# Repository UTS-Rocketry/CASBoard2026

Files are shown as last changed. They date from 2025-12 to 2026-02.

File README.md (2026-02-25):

# CAS Interface Board 2026

Control Actuation System (CAS) Interface Board for the UTS Rocketry avionics stack.

This board provides closed-loop control for the airbrake and roll control systems, along with sensor interfaces and onboard data logging. The design is based on the STM32F405RGT6 microcontroller and integrates inertial sensing, actuator control, and non-volatile storage.

The CAS board is intended to operate as part of the UTS Rocketry flight avionics architecture.

---

## Overview

The CAS Interface Board is responsible for:

- Airbrake deployment control
- Roll stabilization control
- Sensor acquisition
- Data logging
- Actuator interfacing

Closed-loop control is performed onboard using IMU and barometric sensor measurements.

---

## Hardware

### Microcontroller

STM32F405RGT6

- ARM Cortex-M4F
- 168 MHz
- Hardware floating point
- 1 MB Flash
- 192 KB RAM

---

### Sensors

#### IMU

LSM6DS3TR-C

Interface:

- SPI (4-wire)

Signals:

- SCK
- MOSI
- MISO
- CS
- DRDY Interrupt

Power:

- 3.3 V

---

#### Barometer

Interface:

- I2C

Signals:

- SCL
- SDA

Power:

- 3.3 V

---

### Storage

#### MicroSD Card

Interface:

- SPI

Signals:

- SCK
- MOSI
- MISO
- CS

Purpose:

- Flight data logging

---

#### External Flash

Interface:

- SPI

Purpose:

- Backup logging
- Blackbox storage

---

### Actuator Interfaces

#### Servo Outputs

- Airbrake Servo
- Roll Control Servo

Control Method:

- Timer PWM outputs

Power:

- Dedicated 5 V servo rail

Signal Voltage:

- 3.3 V logic

---

### Analog Inputs

#### Airbrake Position Feedback

External potentiometer input.

Signals:

- 3.3 V
- ADC Input
- GND

---

### Digital Inputs

#### Limit Switches

Digital inputs for actuator limits.

Typical configuration:

- External pull-down resistors
- GPIO input

---

#### IMU Interrupt

IMU data-ready interrupt.

Connected to STM32 EXTI input.

---

### Debug Interface

Serial Wire Debug (SWD)

Signals:

- SWDIO
- SWCLK
- NRST
- 3.3 V
- GND

Used for:

- Programming
- Debugging

---

## Communication Interfaces

### SPI Buses

SPI1

Used for:

- IMU

SPI2

Used for:

- MicroSD card
- External flash

---

### I2C Bus

I2C1

Used for:

- Barometer

---

## Power Architecture

### 3.3 V Rail

Supplies:

- MCU
- IMU
- Barometer
- Flash
- SD card logic

---

### 5 V Rail

Supplies:

- Servo motors

---

### Grounding

- Continuous ground plane
- Shared logic and servo ground

---

## Control System

### Airbrake Control

The CAS system predicts apogee using altitude and velocity estimates derived from sensor measurements.

Airbrake deployment is adjusted to reach the target apogee.

Inputs:

- Barometer altitude
- Estimated vertical velocity

Outputs:

- Airbrake servo PWM

---

### Roll Control

Roll stabilization is performed using gyroscope measurements from the IMU.

Inputs:

- Roll rate from IMU

Outputs:

- Roll control servo PWM

---

## Firmware

Development tools:

- STM32CubeMX
- STM32CubeIDE
- ST-Link

Features:

- SPI IMU driver
- I2C barometer driver
- PWM servo control
- SD card logging
- Flash logging
- Interrupt-driven sensor acquisition

---

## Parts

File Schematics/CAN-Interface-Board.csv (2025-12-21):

Reference | Qty | Value | DNP | Exclude from BOM | Exclude from Board | Footprint | Datasheet
0.015Ohm? | 1 | C4293416 |  |  |  |  | ~
10uF? | 1 | C426118 |  |  |  | Capacitor_SMD:C_01005_0402Metric_Pad0.57x0.30mm_HandSolder | ~
100nF1,100nF2,100nF3,100nF? | 4 | C6565120 |  |  |  | Capacitor_SMD:C_1210_3225Metric_Pad1.33x2.70mm_HandSolder | ~
120R? | 1 | C4353191 |  |  |  | Resistor_SMD:R_0603_1608Metric | ~
C15742 | 1 | STM32F405RGTx |  |  |  | Package_QFP:LQFP-64_10x10mm_P0.5mm | https://www.st.com/resource/en/datasheet/stm32f405rg.pdf
INA180A2 | 1 | C192764 |  |  |  | Package_TO_SOT_SMD:SOT-23-5 | http://www.ti.com/lit/ds/symlink/ina180.pdf
LD1117S33TR? | 1 | C86781 |  |  |  | Package_TO_SOT_SMD:SOT-223-3_TabPin2 | http://www.st.com/st-web-ui/static/active/en/resource/technical/document/datasheet/CD00000544.pdf
SN65HVD230 | 1 | C12084 |  |  |  | Package_SO:SOIC-8_3.9x4.9mm_P1.27mm | http://www.ti.com/lit/ds/symlink/sn65hvd230.pdf

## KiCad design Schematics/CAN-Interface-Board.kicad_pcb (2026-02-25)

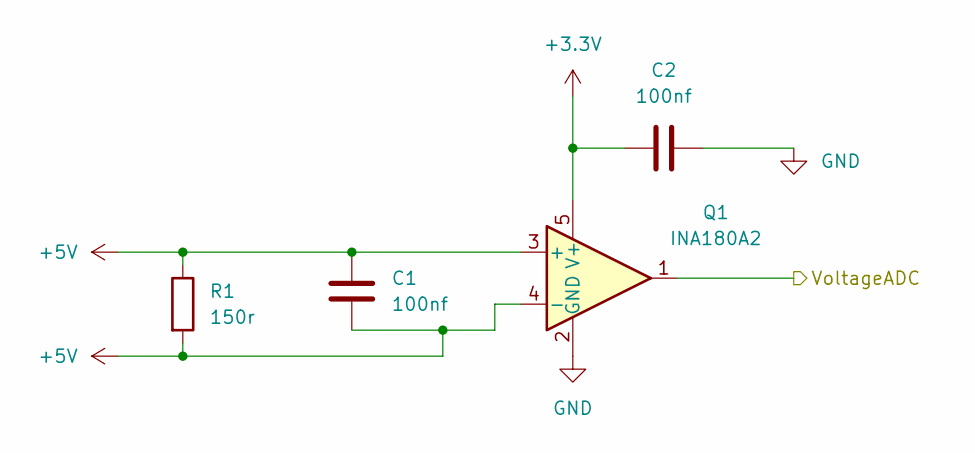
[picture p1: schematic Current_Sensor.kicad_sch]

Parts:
C1, C2: 100nf; C_0805_2012Metric_Pad1.18x1.45mm_HandSolder; LCSC Part C49678
Q1: INA180A2; SOT-23-5; LCSC Part C192764
R1: 150r; R_0805_2012Metric_Pad1.20x1.40mm_HandSolder; LCSC Part C4293416

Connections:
+3.3V: C2.1, Q1.5 (V+); also elsewhere on the board
+5V: C1.1, C1.2, Q1.3 (+), Q1.4 (-), R1.1, R1.2; also elsewhere on the board
/Current Sensor/VoltageADC: Q1.1; also elsewhere on the board
GND: C2.2, Q1.2 (GND); also elsewhere on the board

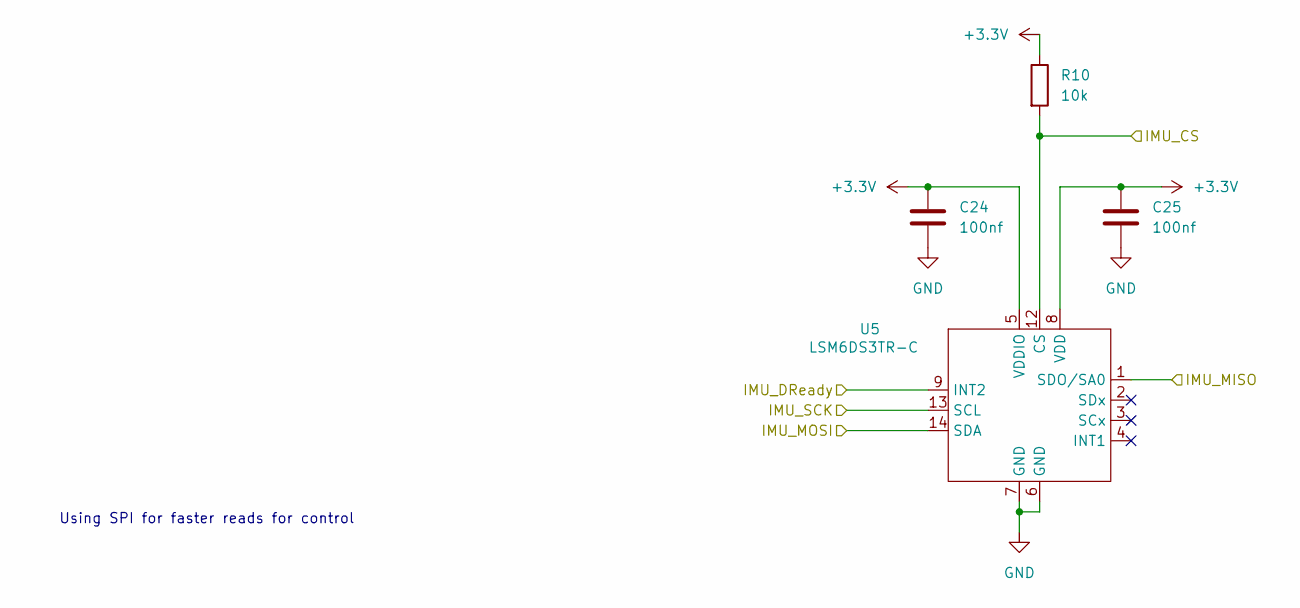
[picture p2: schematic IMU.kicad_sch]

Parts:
C24, C25: 100nf; C_0805_2012Metric_Pad1.18x1.45mm_HandSolder; LCSC Part C49678
R10: 10k; R_0805_2012Metric_Pad1.20x1.40mm_HandSolder; LCSC C84376
U5: LSM6DS3TR-C; LGA-14-2.5X3MM; LCSC Part C967633

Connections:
+3.3V: C24.1, C25.1, R10.1, U5.5 (VDDIO), U5.8 (VDD); also elsewhere on the board
/IMU/IMU_CS: R10.2, U5.12 (CS); also elsewhere on the board
/IMU/IMU_DReady: U5.9 (INT2); also elsewhere on the board
/IMU/IMU_MISO: U5.1 (SDO/SA0); also elsewhere on the board
/IMU/IMU_MOSI: U5.14 (SDA); also elsewhere on the board
/IMU/IMU_SCK: U5.13 (SCL); also elsewhere on the board
GND: C24.2, C25.2, U5.6 (GND), U5.7 (GND); also elsewhere on the board

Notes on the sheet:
Using SPI for faster reads for control

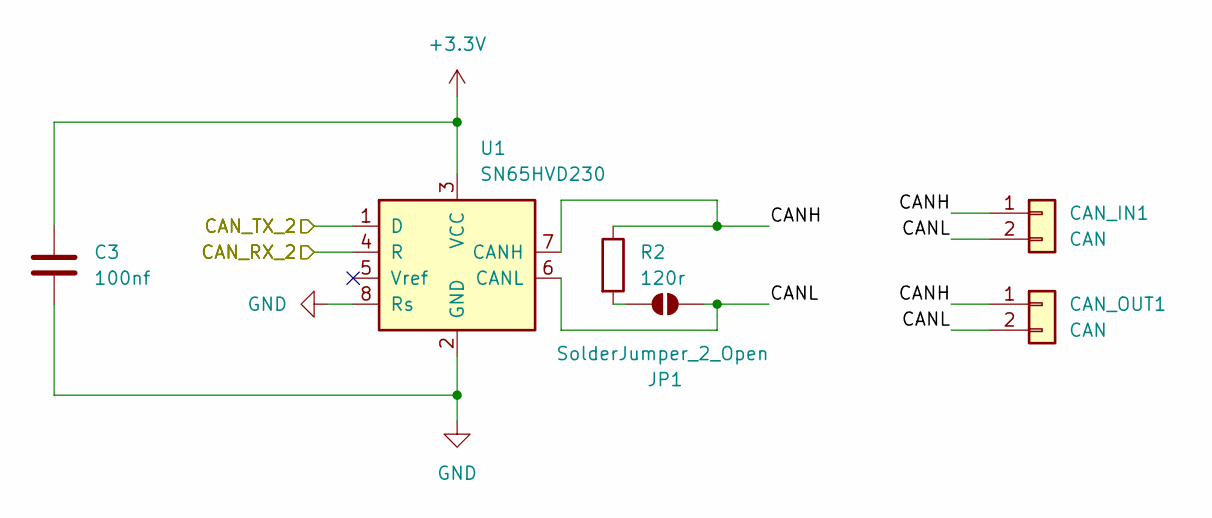
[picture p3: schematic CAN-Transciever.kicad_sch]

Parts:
C3: 100nf; C_0805_2012Metric_Pad1.18x1.45mm_HandSolder; LCSC Part C49678
CAN_IN1: CAN; MOLEX_26013114; LCSC Part C17644051
CAN_OUT1: CAN; MOLEX_26013114; LCSC Part C17644051
JP1: SolderJumper_2_Open; SolderJumper-2_P1.3mm_Open_TrianglePad1.0x1.5mm
R2: 120r; R_0805_2012Metric_Pad1.20x1.40mm_HandSolder; LCSC Part C269726
U1: SN65HVD230; SOIC-8_3.9x4.9mm_P1.27mm; LCSC Part C1543812

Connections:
+3.3V: C3.1, U1.3 (VCC); also elsewhere on the board
/CAN Transciever/CANH: CAN_IN1.1, CAN_OUT1.1, R2.1, U1.7 (CANH)
/CAN Transciever/CANL: CAN_IN1.2, CAN_OUT1.2, JP1.2 (B), U1.6 (CANL)
/CAN Transciever/CAN_RX_2: U1.4 (R); also elsewhere on the board
/CAN Transciever/CAN_TX_2: U1.1 (D); also elsewhere on the board
GND: C3.2, U1.2 (GND), U1.8 (Rs); also elsewhere on the board
unnamed: JP1.1 (A), R2.2

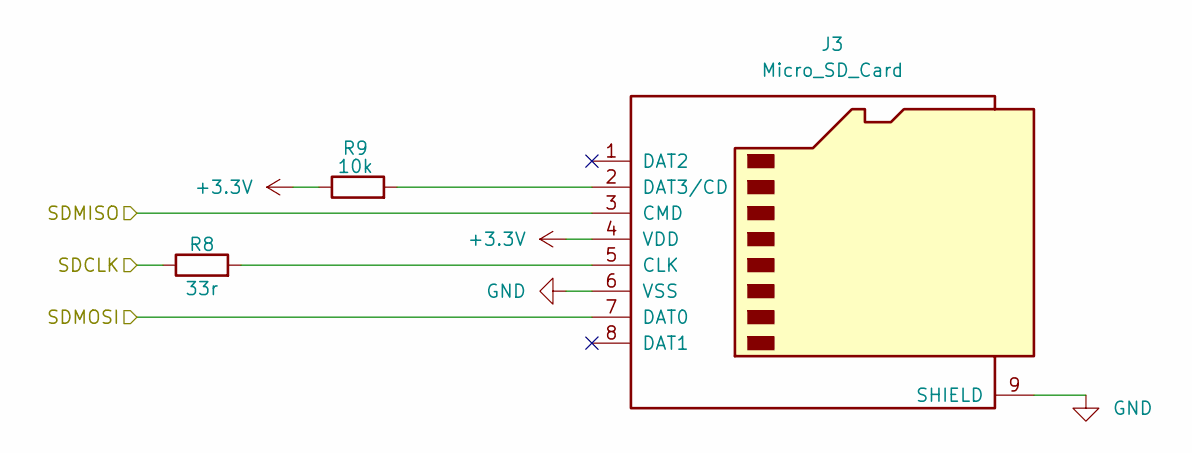
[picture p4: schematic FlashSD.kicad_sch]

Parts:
J3: Micro_SD_Card; microSD_HC_Molex_104031-0811; LCSC Part C164170
R8: 33r; R_0805_2012Metric_Pad1.20x1.40mm_HandSolder; LCSC Part C17557
R9: 10k; R_0805_2012Metric_Pad1.20x1.40mm_HandSolder; LCSC Part C84376

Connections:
+3.3V: J3.4 (VDD), R9.1; also elsewhere on the board
/FlashSD/SDCLK: R8.1; also elsewhere on the board
/FlashSD/SDMISO: J3.3 (CMD); also elsewhere on the board
/FlashSD/SDMOSI: J3.7 (DAT0); also elsewhere on the board
GND: J3.6 (VSS), J3.9 (SHIELD); also elsewhere on the board
unnamed: J3.5 (CLK), R8.2
unnamed: J3.2 (DAT3/CD), R9.2

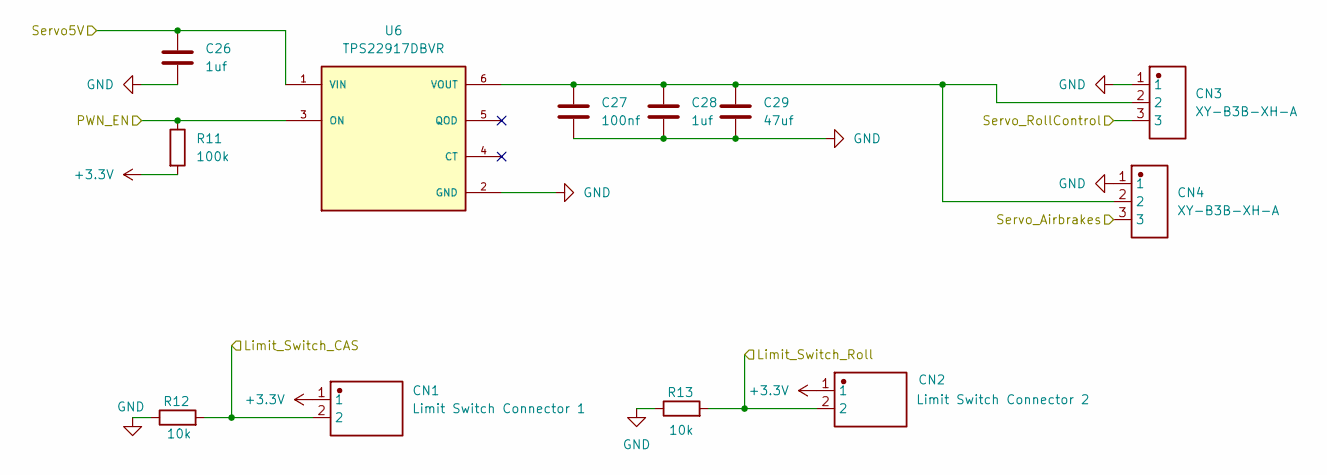
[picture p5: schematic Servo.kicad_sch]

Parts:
C26, C28: 1uf; C_0805_2012Metric_Pad1.18x1.45mm_HandSolder; LCSC C28323
C27: 100nf; C_0805_2012Metric_Pad1.18x1.45mm_HandSolder; LCSC C49678
C29: 47uf; C_0805_2012Metric_Pad1.18x1.45mm_HandSolder; LCSC C16780
CN1: Limit Switch Connector 1; JST_B2B-XH-A_LF__SN_; LCSC Part C158012
CN2: Limit Switch Connector 2; JST_B2B-XH-A_LF__SN_; LCSC Part C158012
CN3, CN4: XY-B3B-XH-A; JST_B3B-XH-A; LCSC Part C51940188
R11: 100k; R_0805_2012Metric_Pad1.20x1.40mm_HandSolder; LCSC C96346
R12, R13: 10k; R_0805_2012Metric_Pad1.20x1.40mm_HandSolder; LCSC Part C4277843
U6: TPS22917DBVR; SOT95P280X145-6N; LCSC C2681320

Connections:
+3.3V: CN1.1, CN2.1, R11.2; also elsewhere on the board
+5V: C26.1, U6.1 (VIN); also elsewhere on the board
/MCU/5Venable: R11.1, U6.3 (ON); also elsewhere on the board
/MCU/LimitSwitchCAS: CN1.2, R12.2; also elsewhere on the board
/MCU/LimitSwitchRoll: CN2.2, R13.2; also elsewhere on the board
/MCU/PWMServo_CAS: CN4.3; also elsewhere on the board
/MCU/PWMServo_Roll: CN3.3; also elsewhere on the board
/Servo/<NO NET>: C27.1, C28.1, C29.1, CN3.2, CN4.2, U6.6 (VOUT)
GND: C26.2, C27.2, C28.2, C29.2, CN3.1, CN4.1, R12.1, R13.1, U6.2 (GND); also elsewhere on the board

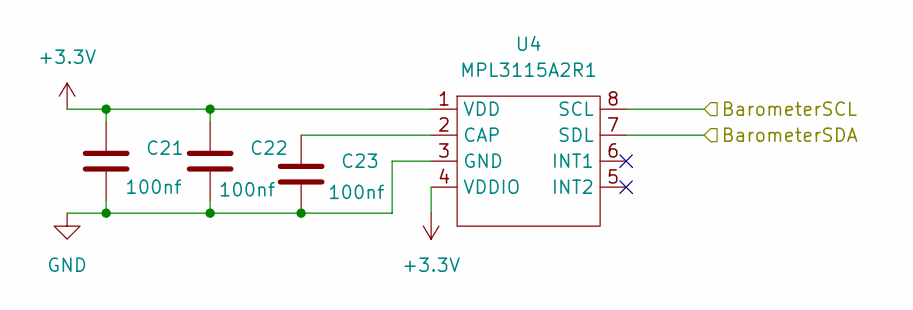
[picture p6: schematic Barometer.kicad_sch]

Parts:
C21, C22, C23: 100nf; C_0805_2012Metric_Pad1.18x1.45mm_HandSolder; LCSC Part C49678
U4: MPL3115A2R1; PSON80P300X300X100-8N; LCSC Part C54429

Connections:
+3.3V: C21.1, C22.1, U4.1 (VDD), U4.4 (VDDIO); also elsewhere on the board
/Barometer/BarometerSCL: U4.8 (SCL); also elsewhere on the board
/Barometer/BarometerSDA: U4.7 (SDL); also elsewhere on the board
GND: C21.2, C22.2, C23.2, U4.3 (GND); also elsewhere on the board
unnamed: C23.1, U4.2 (CAP)

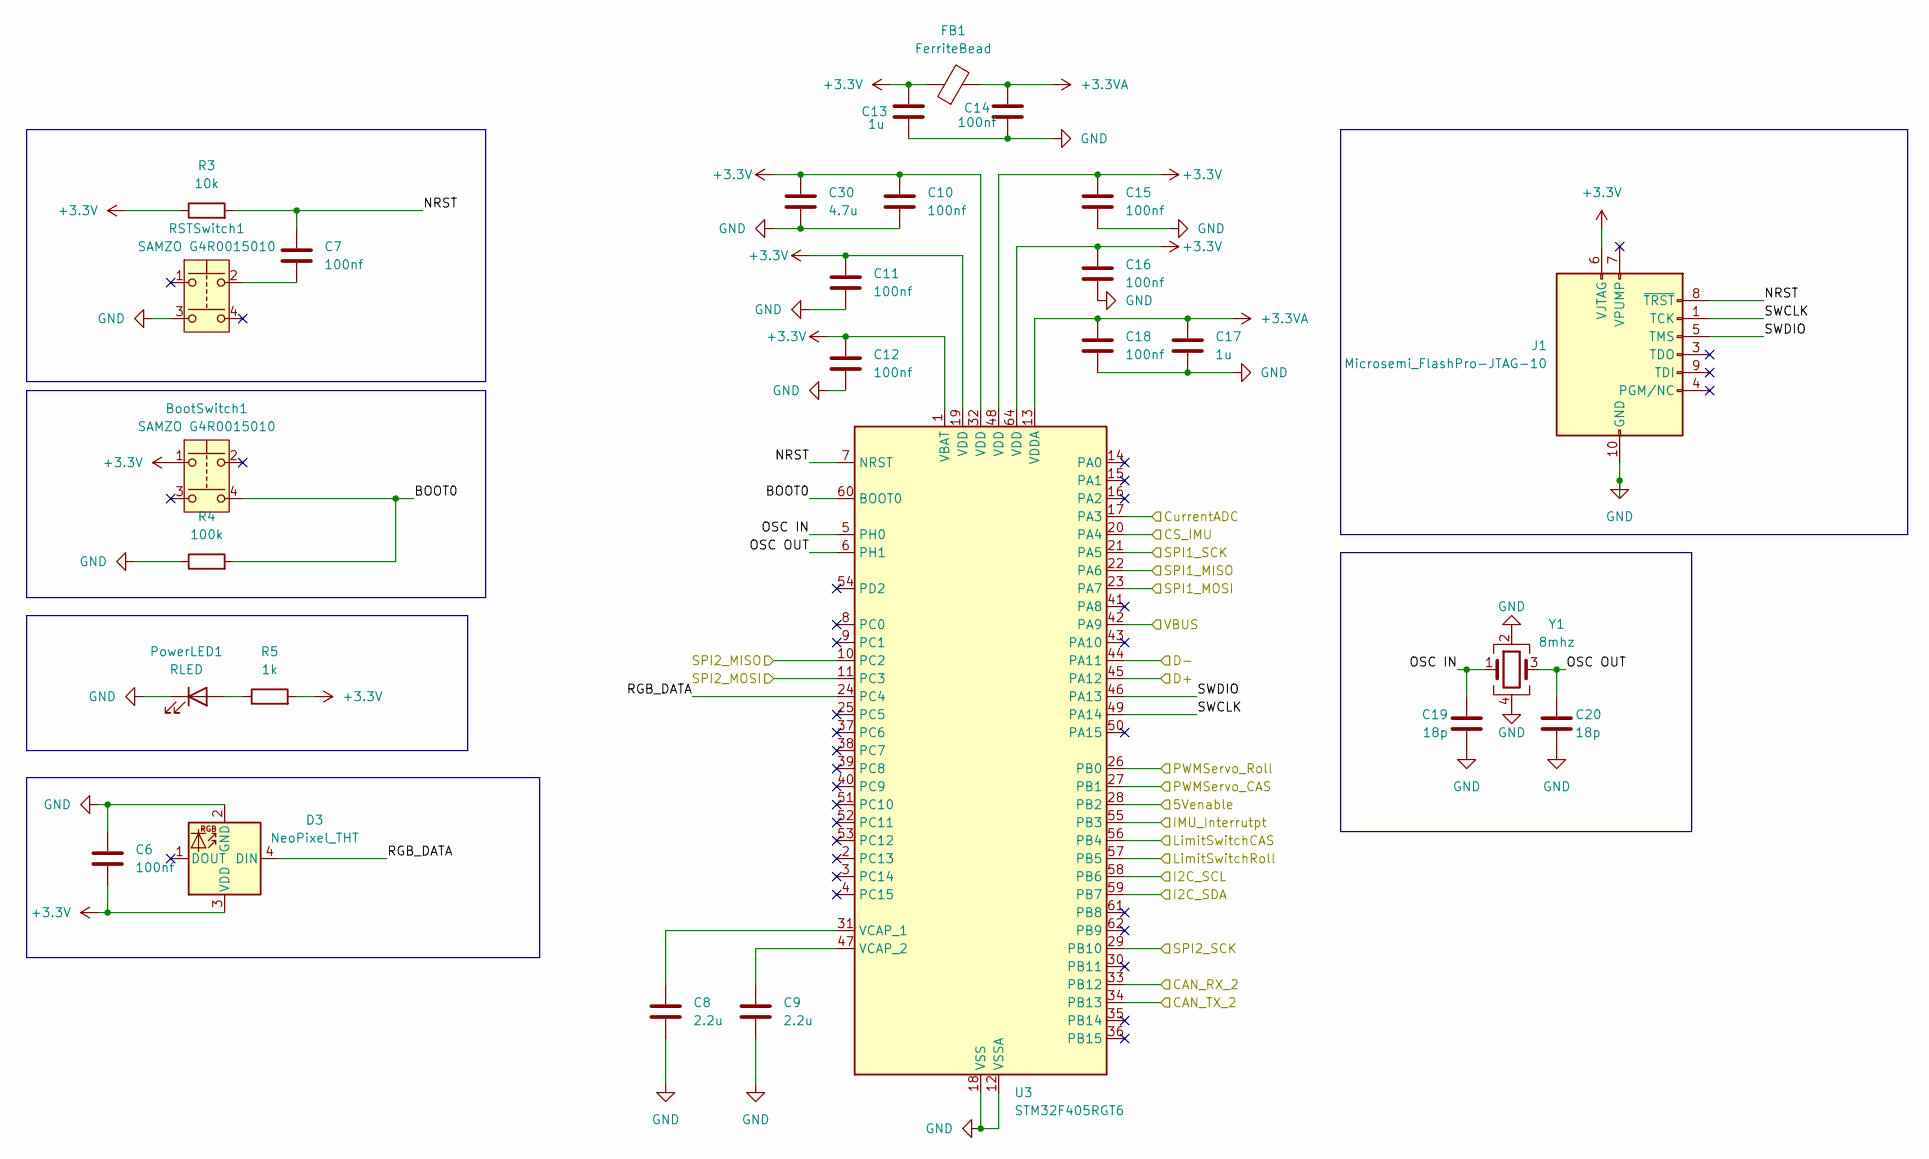
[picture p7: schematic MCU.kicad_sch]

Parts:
BootSwitch1: SAMZO G4R0015010; LCSC Part C49393646
C6, C7: 100nf; C_0805_2012Metric_Pad1.18x1.45mm_HandSolder; LCSC Part C49678
C8, C9: 2.2u; C_0805_2012Metric_Pad1.18x1.45mm_HandSolder; LCSC C19110
C10, C11, C12, C14, C15, C16, C18: 100nf; C_0805_2012Metric_Pad1.18x1.45mm_HandSolder; LCSC C49678
C13, C17: 1u; C_0805_2012Metric_Pad1.18x1.45mm_HandSolder; LCSC C28323
C19, C20: 18p; C_0805_2012Metric_Pad1.18x1.45mm_HandSolder; LCSC Part C170109
C30: 4.7u; C_0805_2012Metric_Pad1.18x1.45mm_HandSolder
D3: NeoPixel_THT; LED_Kingbright_AAA3528ESGCT; LCSC Part C2827321
FB1: FerriteBead; R_0805_2012Metric_Pad1.20x1.40mm_HandSolder; LCSC C85840
J1: Microsemi_FlashPro-JTAG-10; CONN_7024610XX_MOL; LCSC Part C585350
PowerLED1: RLED; LED_0603_1608Metric_Pad1.05x0.95mm_HandSolder; LCSC Part C965799
R3: 10k; R_0805_2012Metric_Pad1.20x1.40mm_HandSolder; LCSC Part C84376
R4: 100k; R_0805_2012Metric_Pad1.20x1.40mm_HandSolder; LCSC Part C96346
R5: 1k; R_0805_2012Metric_Pad1.20x1.40mm_HandSolder; LCSC Part C95781
RSTSwitch1: SAMZO G4R0015010; LCSC Part C49393646
U3: STM32F405RGT6; LQFP-64_10x10mm_P0.5mm; LCSC C15742
Y1: 8mhz; Crystal_SMD_3225-4Pin_3.2x2.5mm_HandSoldering; LCSC Part C19723344

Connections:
+3.3V: BootSwitch1.1, C6.2, C10.1, C11.1, C12.1, C13.2, C15.1, C16.1, C30.1, D3.3 (VDD), FB1.1, J1.6 (VJTAG), R3.1, R5.2, U3.1 (VBAT), U3.19 (VDD), U3.32 (VDD), U3.48 (VDD), U3.64 (VDD); also elsewhere on the board
+3.3VA: C14.2, C17.1, C18.1, FB1.2, U3.13 (VDDA)
/Barometer/BarometerSCL: U3.58 (PB6); also elsewhere on the board
/Barometer/BarometerSDA: U3.59 (PB7); also elsewhere on the board
/CAN Transciever/CAN_RX_2: U3.34 (PB13); also elsewhere on the board
/CAN Transciever/CAN_TX_2: U3.33 (PB12); also elsewhere on the board
/Current Sensor/VoltageADC: U3.17 (PA3); also elsewhere on the board
/FlashSD/SDCLK: U3.29 (PB10); also elsewhere on the board
/FlashSD/SDMISO: U3.10 (PC2); also elsewhere on the board
/FlashSD/SDMOSI: U3.11 (PC3); also elsewhere on the board
/IMU/IMU_CS: U3.20 (PA4); also elsewhere on the board
/IMU/IMU_DReady: U3.55 (PB3); also elsewhere on the board
/IMU/IMU_MISO: U3.22 (PA6); also elsewhere on the board
/IMU/IMU_MOSI: U3.23 (PA7); also elsewhere on the board
/IMU/IMU_SCK: U3.21 (PA5); also elsewhere on the board
/MCU/5Venable: U3.28 (PB2); also elsewhere on the board
/MCU/BOOT0: BootSwitch1.4, R4.2, U3.60 (BOOT0)
/MCU/D+: U3.45 (PA12); also elsewhere on the board
/MCU/D-: U3.44 (PA11); also elsewhere on the board
/MCU/LimitSwitchCAS: U3.56 (PB4); also elsewhere on the board
/MCU/LimitSwitchRoll: U3.57 (PB5); also elsewhere on the board
/MCU/NRST: C7.1, J1.8 (~TRST), R3.2, U3.7 (NRST)
/MCU/OSC IN: C19.1, U3.5 (PH0), Y1.1
/MCU/OSC OUT: C20.1, U3.6 (PH1), Y1.3
/MCU/PWMServo_CAS: U3.27 (PB1); also elsewhere on the board
/MCU/PWMServo_Roll: U3.26 (PB0); also elsewhere on the board
/MCU/RGB_DATA: D3.4 (DIN), U3.24 (PC4)
/MCU/SWCLK: J1.1 (TCK), U3.49 (PA14)
/MCU/SWDIO: J1.5 (TMS), U3.46 (PA13)
/USB5V: U3.42 (PA9); also elsewhere on the board
GND: C6.1, C8.2, C9.2, C10.2, C11.2, C12.2, C13.1, C14.1, C15.2, C16.2, C17.2, C18.2, C19.2, C20.2, C30.2, D3.2 (GND), J1.2 (GND), J1.10 (GND), PowerLED1.1 (K), R4.1, RSTSwitch1.3, U3.12 (VSSA), U3.18 (VSS), U3.63 (VSS), Y1.2, Y1.4; also elsewhere on the board
unnamed: C7.2, RSTSwitch1.2
unnamed: PowerLED1.2 (A), R5.1
unnamed: C8.1, U3.31 (VCAP_1)
unnamed: C9.1, U3.47 (VCAP_2)

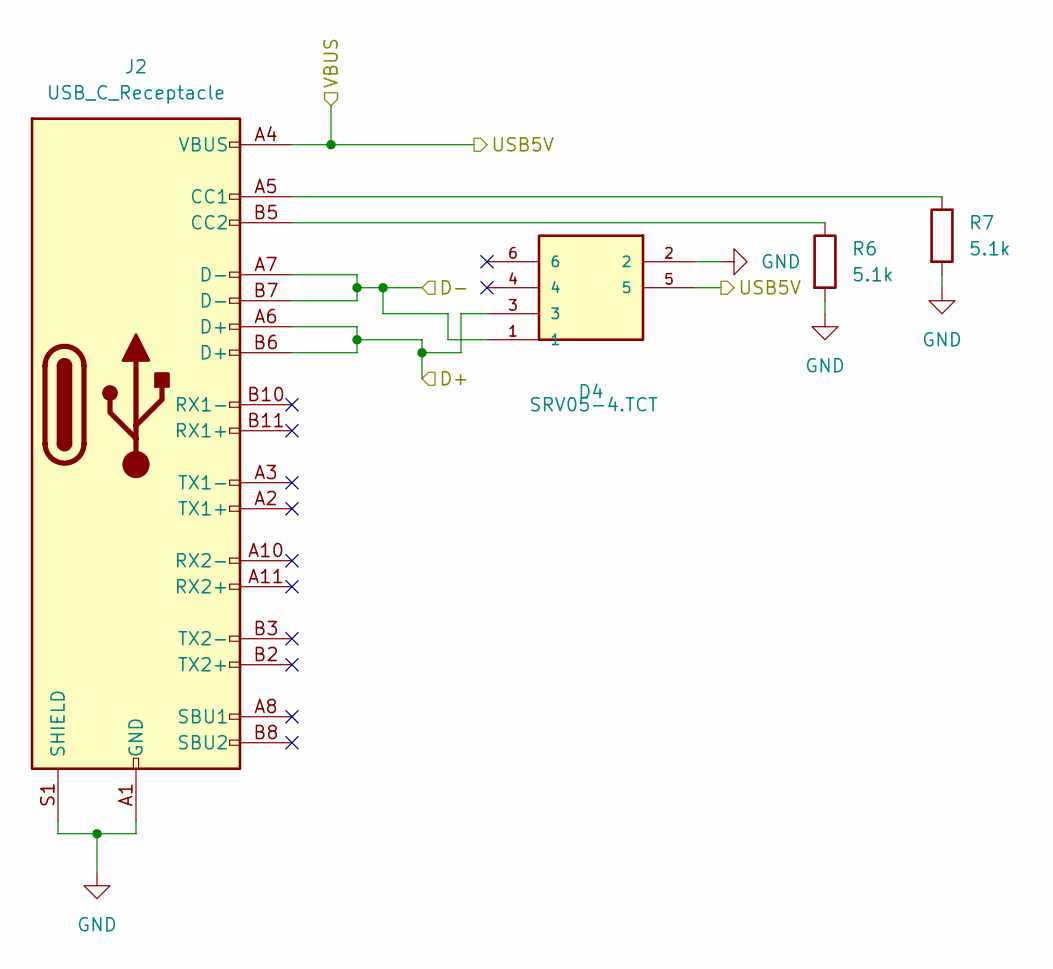
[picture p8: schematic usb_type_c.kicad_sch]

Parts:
D4: SRV05-4.TCT; SOT-23-6_L2.9-W1.6-P0.95-LS2.8-BR; MOUSER_PART_NUMBER 947-SRV05-4.TCT
J2: USB_C_Receptacle; USB_C_Receptacle_HRO_TYPE-C-31-M-12; LCSC C49566391
R6, R7: 5.1k; R_0805_2012Metric_Pad1.20x1.40mm_HandSolder; LCSC C27834

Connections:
/MCU/D+: D4.3, J2.A6 (D+), J2.B6 (D+); also elsewhere on the board
/MCU/D-: D4.1, J2.A7 (D-), J2.B7 (D-); also elsewhere on the board
/USB5V: D4.5, J2.A4 (VBUS), J2.A9 (VBUS), J2.B4 (VBUS), J2.B9 (VBUS); also elsewhere on the board
GND: D4.2, J2.A1 (GND), J2.A12 (GND), J2.B1 (GND), J2.B12 (GND), J2.S1 (SHIELD), R6.2, R7.2; also elsewhere on the board
unnamed: J2.A5 (CC1), R7.1
unnamed: J2.B5 (CC2), R6.1

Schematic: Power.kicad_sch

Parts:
C4: 1u; C_0805_2012Metric_Pad1.18x1.45mm_HandSolder; LCSC Part C28323
C5: 4.7u; C_0805_2012Metric_Pad1.18x1.45mm_HandSolder; LCSC Part C98192
D1, D2: D_Schottky; D_2114_3652Metric; LCSC C113936
J_BUCK_IN_A1: PinSocket_1x02_P2.54mm_Horizontal
J_BUCK_IN_B1: PinSocket_1x02_P2.54mm_Horizontal
J_BUCK_OUT_A1: PinSocket_1x02_P2.54mm_Horizontal
J_BUCK_OUT_B1: PinSocket_1x02_P2.54mm_Horizontal
PowerIn1: 2 pin Molex; MOLEX_26013114; LCSC C17644051
U2: LDL1117-3.3; SOT230P700X180-4N; LCSC C435835

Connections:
+3.3V: C5.1, U2.3 (Vout), U2.4 (Vout); also elsewhere on the board
+5V: J_BUCK_OUT_B1.1, J_BUCK_OUT_B1.2; also elsewhere on the board
+BATT: D1.2 (A), J_BUCK_IN_B1.1, J_BUCK_IN_B1.2, PowerIn1.1
/USB5V: D2.2 (A); also elsewhere on the board
GND: C4.2, C5.2, J_BUCK_IN_A1.1, J_BUCK_IN_A1.2, J_BUCK_OUT_A1.1, J_BUCK_OUT_A1.2, PowerIn1.2, U2.2 (GND); also elsewhere on the board
unnamed: C4.1, D1.1 (K), D2.1 (K), U2.1 (Vin)

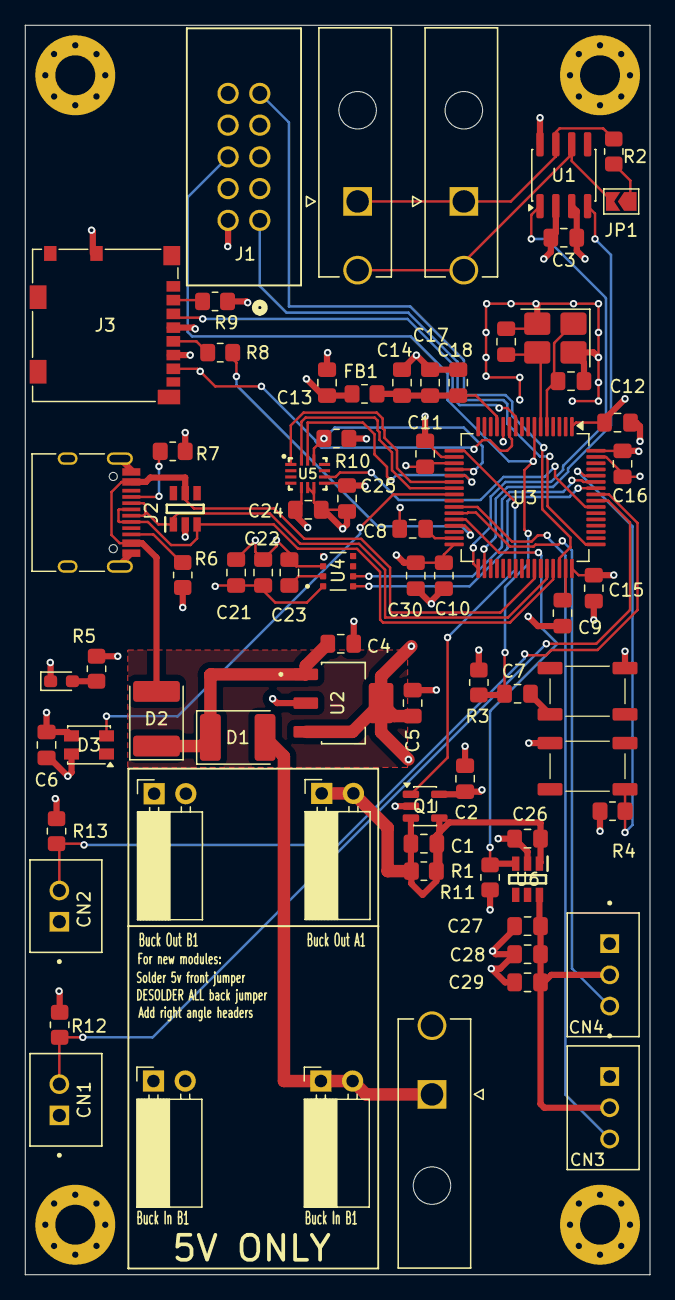
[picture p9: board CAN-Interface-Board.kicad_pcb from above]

Board: 4 copper layers, 50.0 x 100.0 mm, 74 parts (0 on the bottom side), 47 nets.

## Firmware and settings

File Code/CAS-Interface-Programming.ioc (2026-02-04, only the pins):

Mcu.UserName=STM32F405RGTx
PA0-WKUP.Signal=ADCx_IN0
PA1.Signal=ADCx_IN1
PA13.Signal=SYS_JTMS-SWDIO
PA14.Signal=SYS_JTCK-SWCLK
PA3.Signal=ADCx_IN3
PA5.Signal=GPIO_Output
PA7.Signal=S_TIM14_CH1
PB12.Signal=CAN2_RX
PB13.Signal=CAN2_TX
PC4.Signal=GPIO_Output

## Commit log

2026-02-04 altered connectors, layout refinement, added LEDS
    [CAN-Interface-Board.kicad_pcb, CAN-Transciever.kicad_sch, Current_Sensor.kicad_sch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]
2026-02-04 STM32IDE Project Added
2026-02-15 Began conversion for full CAS Control
    [Accelerometer.kicad_sch, Barometer.kicad_sch, CAN-Interface-Board.kicad_sch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]
2026-02-22 altered sensor schematics
    [Accelerometer.kicad_sch, CAN-Interface-Board.kicad_sch]
2026-02-24 editing schematic
    [CAN-Interface-Board.kicad_pcb, CAN-Interface-Board.kicad_sch, CAN-Transciever.kicad_sch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]
2026-02-24 cleaned up repo
    [Barometer.kicad_sch, CAN-Interface-Board.csv, CAN-Interface-Board.kicad_pcb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]
2026-02-25 finished and ERC schematic
    [Barometer.kicad_sch, CAN-Interface-Board.kicad_sch, CAN-Transciever.kicad_sch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]
2026-02-25 inital layout started, refining stage
    [CAN-Interface-Board.kicad_pcb, Current_Sensor.kicad_sch, MCU.kicad_sch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]
2026-02-25 first round of routing complete need to pass DRC first and need to reroute more effiencently
    [CAN-Interface-Board.kicad_pcb]
2026-02-25 fixed schematic
    [CAN-Interface-Board.kicad_sch, IMU.kicad_sch, usb_type_c.kicad_sch]
2026-02-25 put note to fix nets on current sensor
    [Current_Sensor.kicad_sch]
